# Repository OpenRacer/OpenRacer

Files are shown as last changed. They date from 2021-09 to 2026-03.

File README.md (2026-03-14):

<h3>OpenRacer - An open source frame with 3D printed canopy for racing and freestyle.</h3>
<hr>

<h3>Support OpenRacer</h3>

If you would like to support the development of OpenRacer please feel free to make a small [donation](https://www.paypal.com/donate/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). This helps us pay for prototyping/testing of carbon and canopies. When you donate, feel free to leave a comment what additions would you like to see next.

[DONATE](https://www.paypal.com/donate/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)

Full frame kits are sold by [Five33](https://flyfive33.com/products/five33-open-racer-frame-kit-1?wpam_id=17) (aff. link). You can also order the carbon from [CNC Madness](https://cncmadness.com/). We provide instructions for printing your own canopy, but if you would like one printed we recommend [Phoenix 3D](https://www.phx-3d.com/). Carbon files are for 5 inch props unless otherwise specified.

<h3>Useful Links</h3>

STL and DXF files are [here.](https://github.com/OpenRacer/OpenRacer/tree/master/cad)<br>
[Join our Facebook group](https://www.facebook.com/groups/640824090407985)<br>
[Buy frame at Five33](https://flyfive33.com/products/five33-open-racer-frame-kit-1?wpam_id=17)<br>
[Freestyle example with GP7](https://www.youtube.com/watch?v=OqChCLXAk6A)<br>
[Racing example with GP7](https://www.youtube.com/watch?v=VN75sF9umTA)<br>
[Racing full speed no gopro](https://www.youtube.com/watch?v=_SSzJq6VKVc)<br>
[DJI racing example](https://www.youtube.com/watch?v=-WxEIBV4bSs)<br>
[Review by Jon E5](https://www.youtube.com/watch?v=laAqQoRC8uU)<br>
[Step-by-step build video by Jon E5](https://youtu.be/wqulm-HaGHg)<br>
<hr>

This design was created from scratch but inspired by the brilliant CampfireQuads frame. Since the Campfire frame isn't open source and pilots wanted to improve the design to add features like support for a Caddx Vista, the OpenRacer frame was created to share with the FPV community. This design has been tested thoroughly by the community, but we're still looking for ways to improve it. Please contribute ideas or submit your own designs through pull requests!

**Note:** A lightweight variant of this frame is available – see [JM OpenRacer Light](JM_OpenRacer_Light_README.md) for details.<br><br>

<h3>Recommended carbon thickness</h3>

```
Top and Bottom plates: 2.5mm
Arms: 5mm
Braces: 4mm
```

<h3>Required screws, nuts, and standoffs</h3>

```
- 8x pressnuts M3 (for top plate)
- 4x standoffs 10mm M3 (to mount canopy) rough surface preferably
- M3 plastic nuts X 4 (to secure FC/stack)

Titanium (Grade alloy if titanium not available):
- M3 Button head 12mm X 8 (mount motors through braces and arms)
- M3 Button head 8mm X 4 (mount motors through arms)
- M3 Button head 6mm X 4 (secure canopy from the top)

Alloy Steel (12.9 Gauge Alloy - the best. 10.9 grade also works.
Not aluminium, not titanium, not stainless steel)
- M3 Countersunk 16mm X 4 (arm mounting, goes through both plates, pressnut and standoff)
- M3 Countersunk 30mm X 4 (for 30x30 stack, goes through both plates)

Additional hardware for 20x20 stack builds:
- M3 Countersunk 12.9 Grade Alloy 12mm X 4 (to lock the arms instead of 30x30 stack screws)
- M3 Button head 20mm X 4 (Titanuim or Grade Alloy) (for 20x20 stack)

Extra for 25x25 AIO:
- M2 Button head 12mm X 4
```

All canopies can be printed in 95A shore hardness TPU with the exception of the AnalogPro version. The AnalogPro canopy should be printed in Nylon. A Nylon similar to Taulman 645 is preferred, but for printers with PTFE-lined hotends limited to <250C temperatures, Taulman's lower temp alternatives such as Bridge, 230, or PCTPE are also good choices. If you are unfamiliar with Nylon printing, it has some challenges associated. Drying the filament and keeping it dry is very important, but steps for that will not be covered here.
Taulman recommends 40-60C bed temperature for PCTPE, but some people report that running even lower temperatures (35C) can help avoid warping and adhesion issues. 
Nylon prints should be boiled in water for 5 minutes to restore their flexibility.

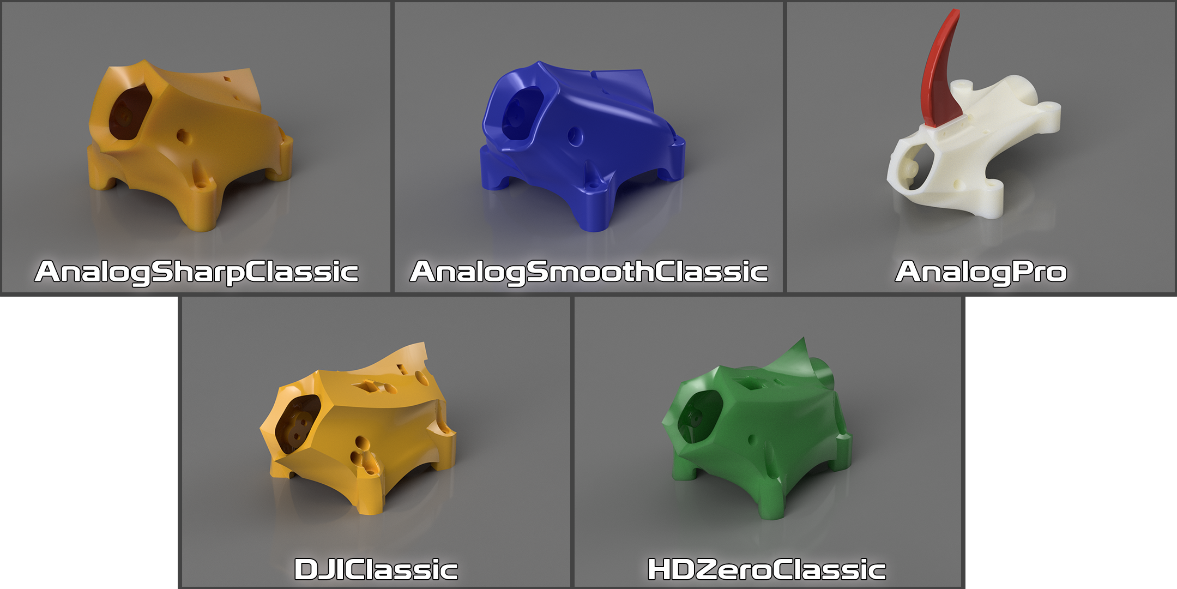
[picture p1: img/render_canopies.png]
Canopy versions


<h3>Suggested print settings for TPU canopies</h3>

```
1.6mm wall thickness (for 0.4mm nozzle, use 0.53mm line width and 3 perimeters to achieve 1.59mm walls. 0.6 to 0.8mm nozzles will use 0.8mm line width and 2 perimeters)
0.2mm layer height recommended, 0.28mm maximum
30-60% fan speed
20% infill (gyroid if available)
Supports are required
Recommended orientation is with standoff legs on the bed. It's possible to print some canopies on the nose to reduce support material, but this can be tricky and has cosmetic disadvantages.
```

<h3>Suggested print settings for Nylon AnalogPro canopies</h3>

```
1.6mm wall thickness (for 0.4mm nozzle, use 0.53mm line width and 3 perimeters to achieve 1.59mm walls. 0.6 to 0.8mm nozzles will use 0.8mm line width and 2 perimeters)
0.2mm layer height recommended, 0.28mm maximum
0% fan speed
20% infill
Supports are required, but only from build plate
Recommended print orientation is with standoff legs on bed. Use care removing supports around the antenna holder. 
```

<h3>Canopy Accessories</h3>

The AnalogPro canopy has a slot on top for an optional fin, which can help when using turtle (flip over after crash) mode. It's recommended to print this part in 95A TPU. If a camera locker is available for a canopy, it will be in the CameraLockers folder for the associated canopy. Camera lockers help maintain your camera angle in crashes and also provide some level of protection.

<p>

AnalogSharpClassic and AnalogSmoothClassic versions work with most of normal 20x20 and 30x30 stacks. 

<p>

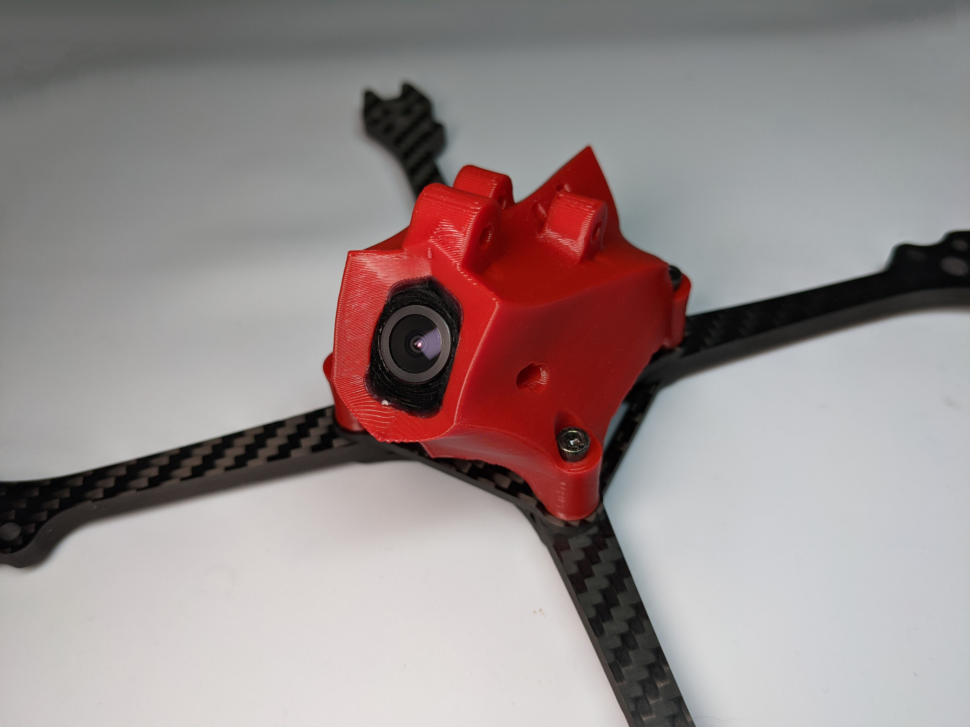
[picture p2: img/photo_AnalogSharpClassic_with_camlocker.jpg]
TPU AnalogSharpClassic

<sub>AnalogSharpClassic with optional GoPro mounts and camera locker.</sub>

<h3>Recommended components for the AnalogPro version</h3>

```
Arms style: Fatty
Canopy Style: PRO - predator nano V5
FC:        Foxeer 20x20 V2
ESC:       Foxeer Reaper 45A or 60A 20x20
Camera:    Foxeer Predator nano V5
VTX:       Rush Tiny Tank
Motors:    Vanover V2 or Headsup
Props:     Dal new Cyclone V2
Batteries: Rline v4 1300Mah 6S or any good brand like Pyroflip, GNB
Antenna:   U.FL TO SMA EXTENSION and small antenna like TrueRc
RX:        Matching RX for your radio. Ghost, Tracer, ELRS, Crossfire, etc.
Other:     Optional short race wires like Pyro race wires, zip ties, double side tape, heatshrink
```

<h3>Recommended components for the Classic versions</h3>

```
FC:        Clracing F7
ESC:       Any 30x30 Blheli32 ESC that is not very big like Spedix, Hobbywing etc. starting from 35A. Be careful, modern 30x30 Aikon and Clracing ESCs are too big. 
Camera:    Runcam Racer 3 or Foxeer Predator Micro V4
VTX:       Rush Tiny Tank
Motors:    RCINPOWER GTS-V2 2207PLUS 2207 1860KV or Vanover Motors or Talon
Props:     Gemfan 51466X3 Hurricane
Batteries: Rline v3 1300Mah 6S or any good brand like Pyroflip, GNB
Antenna:   U.FL TO SMA EXTENSION and small antenna like TrueRc
RX:        Matching RX for your radio. Ghost, Tracer, ELRS, Crossfire, etc.
Other:     Optional short race wires like Pyro race wires, zip ties, double side tape, heatshrink
```

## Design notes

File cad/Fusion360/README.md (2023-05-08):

# Fusion 360 files
These files may be used to create new canopies.
Not every canopy has an associated Fusion 360 file. To request CAD files please open an issue.

**WARNING:** Create a new folder before opening these files, as they contain many components.

## HDZero Clasic Parametric
[Download here](HDZero_Tank_V2_Parametric_v3.f3z)

This is the Fusion file for the HDZero Classic canopy.
It has parameters which let you set the size of the camera, body, lens, etc.
Please note that this is not well-tested, and currently contains parameters for the Runcam Nano 90 camera.
Activate the final two features in the design history to slice the canopy into a small printable test area.

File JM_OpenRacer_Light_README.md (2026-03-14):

# JazzMutant's OpenRacer Light

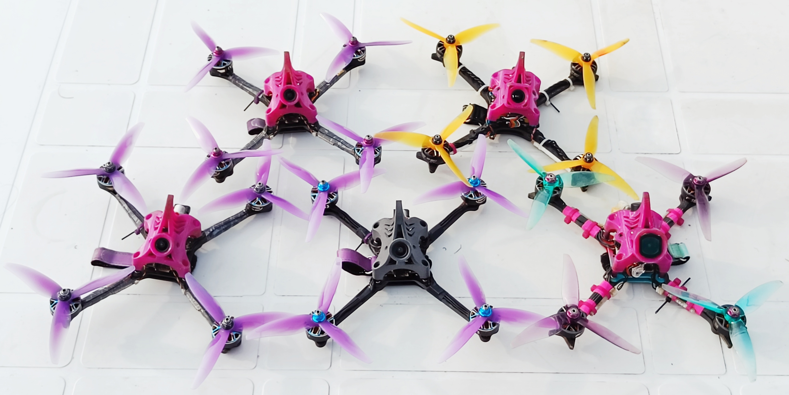
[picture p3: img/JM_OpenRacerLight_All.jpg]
JM OpenRacer Light


## Overview

The **JM OpenRacer Light** is a fully backward-compatible lightweight version of the original OpenRacer frame, designed for pilots who want reduced weight without sacrificing durability or maintainability. This version maintains full mounting compatibility with standard OpenRacer parts while implementing optimizations in the carbon structure.

This frame works best with the "OpenRacer 5 6S by JazzMutant" Betaflight preset for optimal performance.

## Canopies 

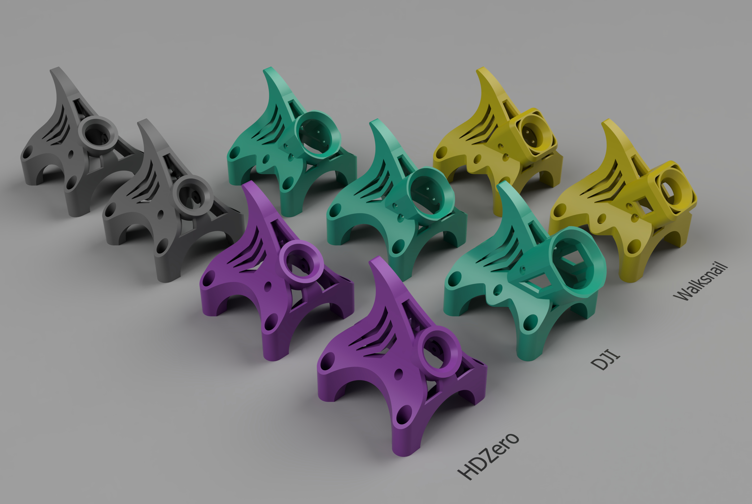
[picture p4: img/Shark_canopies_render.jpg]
Shark Canopies


This frame works with all existing OpenRacer canopies. In addition, **@jares13** have disigned the **Shark Canopies** which are lighter than the standard designs and remain extremely durable. They also feature an integrated fin for turtle‑mode recovery.

### Options
```
- HDZero Race V3 + Nano 90 v2 + Rush Cherry v2. (45° or 55°)
- DJI O3 (45°)
- DJI O4 light + O3 lens (45°)
- DJI O4 pro + O3 antenna (45°)
- Walksnail Avatar Pro (45°)
- Walksnail Avatar v2 (45°)
```

If you need more canopy variants for specific hardware or personal preference, a **Fusion 360 project** is provided to let you customize or generate additional designs.

### Printing Recommendations

All canopies for the Light frame should be printed in **95A TPU**.
There is also an HDZero version optimized for PA-11 nylon which is thinner and lighter. For nylon printing, services such as PCBWay and JLC3DP are recommended.

## Hardware Specifications

### Carbon

```
Top Plate:          2mm
Bottom Plate:       2mm
Arms:               5mm
Braces (optional):  3-4mm
```

**Important**: All carbon components should be **T700 carbon fiber** to compensate for the reduced thickness and ensure optimal strength-to-weight ratio. Braces are optional and can be either 3mm or 4mm thick depending on your build preference.

### Required Hardware

**HDZero Race V3 with 20x20 stack**
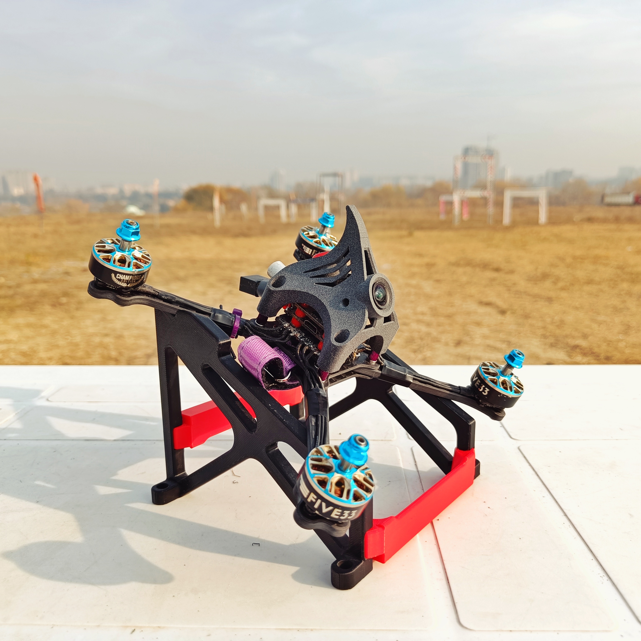
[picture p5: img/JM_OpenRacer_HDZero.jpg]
JM OpenRacer HDZero

```
8 psc   M3 pressnuts (for top plate)
4 psc   M3 nut (for stack screws. Titanium)
4 psc   M3x25mm button head screw (for stack mounting. Titanium)
4 psc   M3x10mm countersunk screw (for arm mounting. 12.9 grade alloy steel)
4 psc   M3x16mm countersunk screw (for arm and standoff mounting. 12.9 grade alloy steel)
4 psc   M3x6mm button head screw (for canopy mounting. Titanium)
12 psc  M3x8mm button head screw (for motors mounting. Titanium)
4 psc   M3x10mm standoff.
```

**DJI/Walksnail with 20x20 stack**
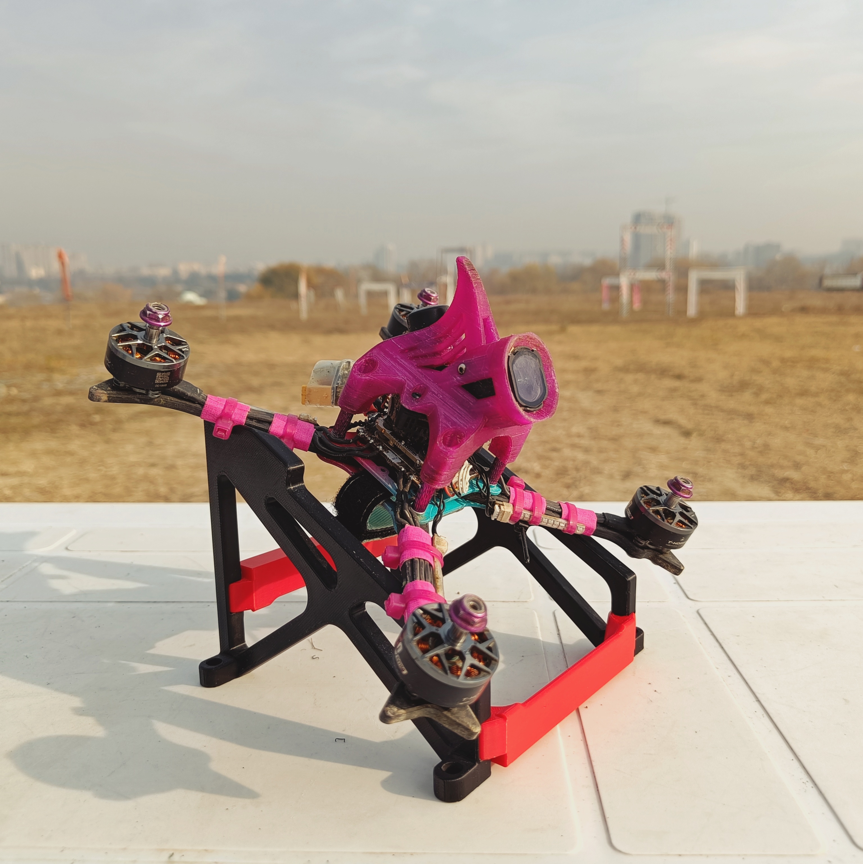
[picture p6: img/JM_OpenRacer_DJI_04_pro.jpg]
JM OpenRacer DJI 04 pro

```
8 psc   M3 pressnuts (for top plate)
4 psc   M3 nut (for stack screws. Titanium)
4 psc   M3x18mm button head screw (for stack mounting. Titanium)
4 psc   M3x10mm countersunk screw (for arm mounting. 12.9 grade alloy steel)
4 psc   M3x16mm countersunk screw (for arm and standoff mounting. 12.9 grade alloy steel)
4 psc   M3x6mm button head screw (for canopy mounting. Titanium)
12 psc  M3x8mm button head screw (for motors mounting. Titanium)
4 psc   M3x15mm standoff.
```

**Optional hardware**
```
8 psc   M3x12mm button head screw (for motor mounting if you use braces)
8 psc   M3x28mm countersunk screw (for arm and stack mounting if you use 30x30 stack. 12.9 grade alloy steel)
4 psc   M2x12mm button head screw (for AIO mounting)
```

**Notes:**
- Use 12.9 grade alloy steel for arm mounting. Anything else would not work.
- Titanium is recommended for best weight savings but can be replaced with steel.

## Reference Builds

> **Disclaimer:** these example builds are provided for illustration only and use different component sets; they should not be treated as directly comparable or definitive "best" configurations.

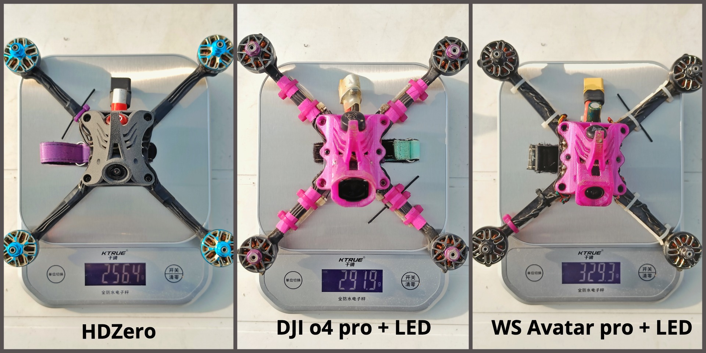
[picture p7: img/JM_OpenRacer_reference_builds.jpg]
Reference Builds


### HDZero

- Frame: JM OpenRacer Light
- Stack: Oxbot Champ (20×20)
- Motors: Five33 2207 2070 KV
- Camera: HDZero Nano 90 V2
- VTX: HDZero Race V3
- Antenna: Rush Cherry V2
- RC: Radiomaster XR1
- Canopy: Shark Canopy (Nylon)

**Weight: 256.4g**

---

### DJI O4 Pro

- Frame: JM OpenRacer Light
- Stack: HDZero Halo (20×20)
- Motors: T-Motor F50 2207 2150 KV
- Camera: DJI O4 Pro
- VTX: DJI O4 Pro
- Antenna: DJI O3
- Canopy: Shark Canopy (95A TPU)
- Other: HGLRC LED Kit

**Weight: 291.9g**

---

### Walksnail Avatar Pro

- Frame: Default OpenRacer (steel hardware)
- Stack: SpeedyBee V4 (30×30)
- Motors: iFlight XING E-Pro 2207 2450 KV
- Camera: Walksnail Avatar Pro
- VTX: Walksnail Avatar Pro
- Antenna: Walksnail
- RC: Happymodel EP1
- Canopy: Shark Canopy (95A TPU)
- Other: LED Kit

**Weight: 329.3g**
This is a temporary file containing the Flight Videos section to append to the README.

## Flight Videos

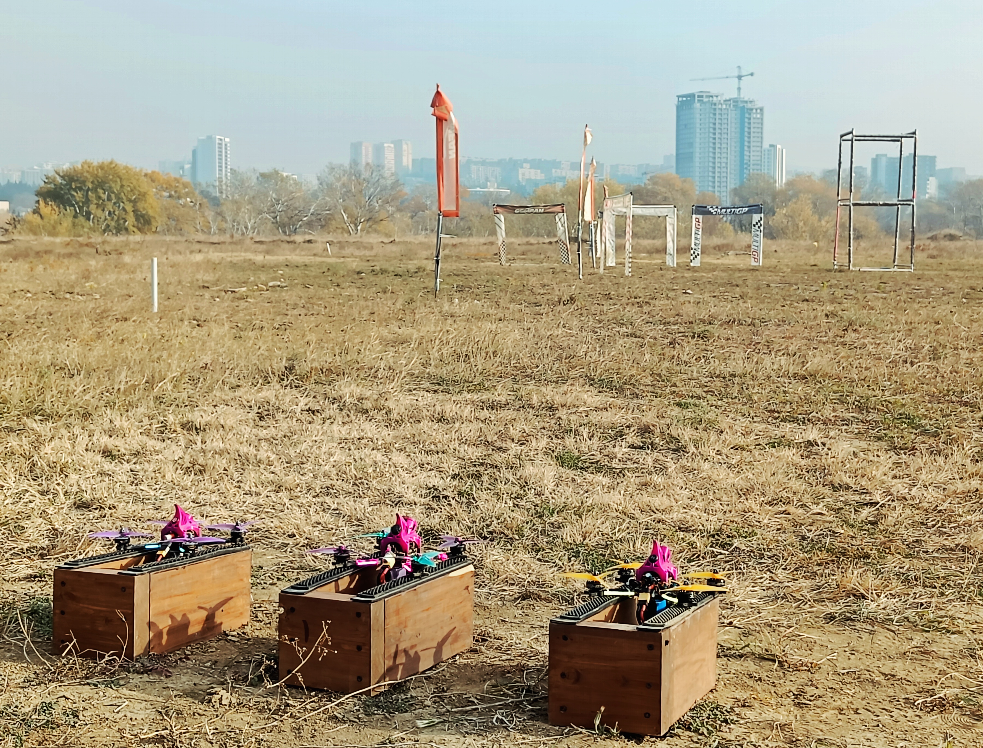
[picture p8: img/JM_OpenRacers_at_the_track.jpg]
JM OpenRacers at the track


Here are some flight footages from our practice sessions:
- [Sunday Mayhem](https://youtu.be/KUW6h_FZijc)

- [NIGHT PRACTICE](https://youtu.be/jPU3IjdKNmI)

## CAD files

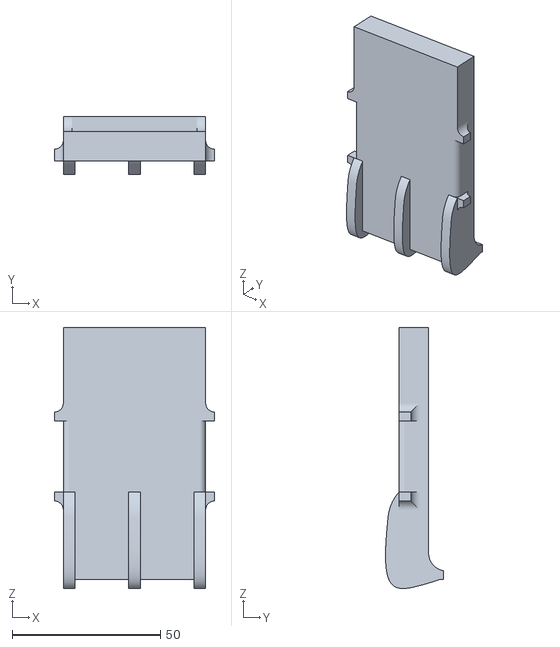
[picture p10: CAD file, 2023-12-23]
cad/Accessories/6S_LiPo_Coffin_Wider.stl
54.0 x 19.5 x 88.0

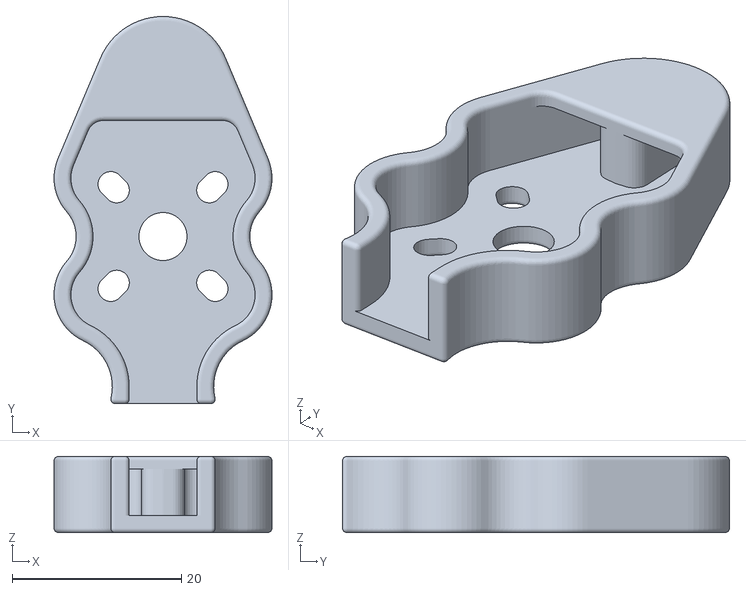
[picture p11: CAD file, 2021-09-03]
cad/Accessories/ShoesTpu/ClassicArms/4holesArmShoe.stl
25.8 x 45.8 x 9.00

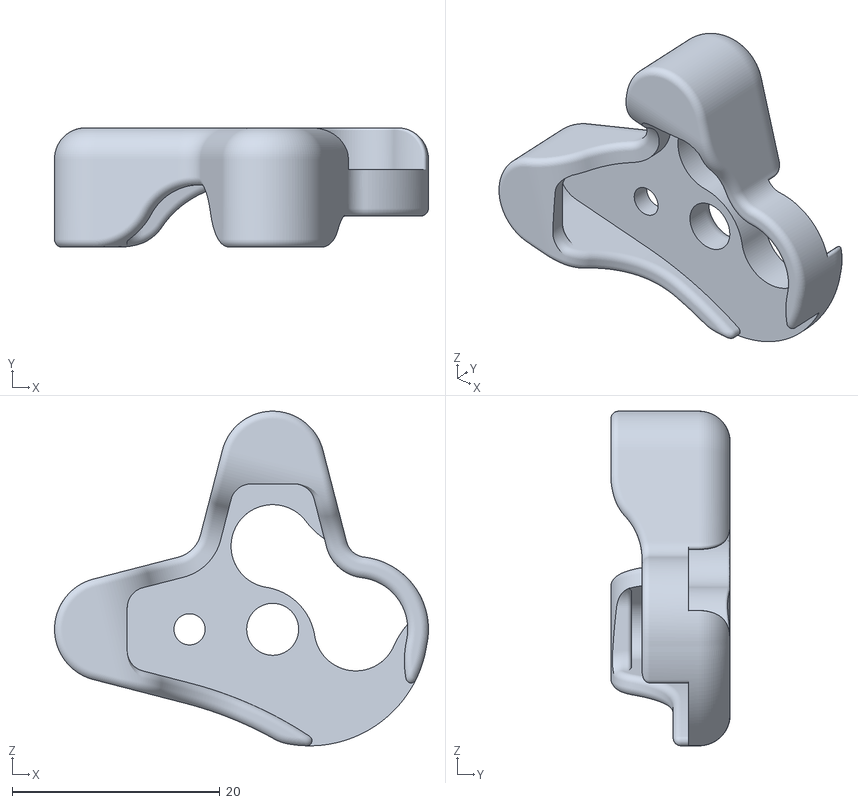
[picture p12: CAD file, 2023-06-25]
cad/Accessories/ShoesTpu/XvOrFattyArms/Xvlite_shoe.stl
36.0 x 11.5 x 32.2

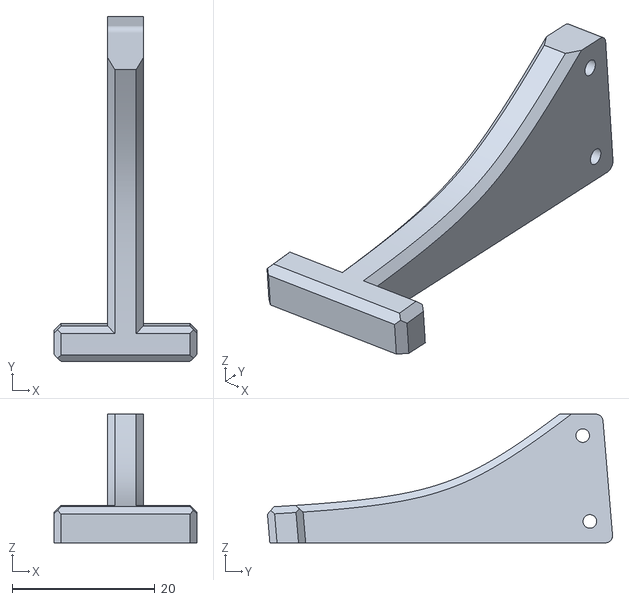
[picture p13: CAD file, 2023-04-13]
cad/AnalogPro/Fins/T-fin.stl
20.0 x 48.3 x 18.0

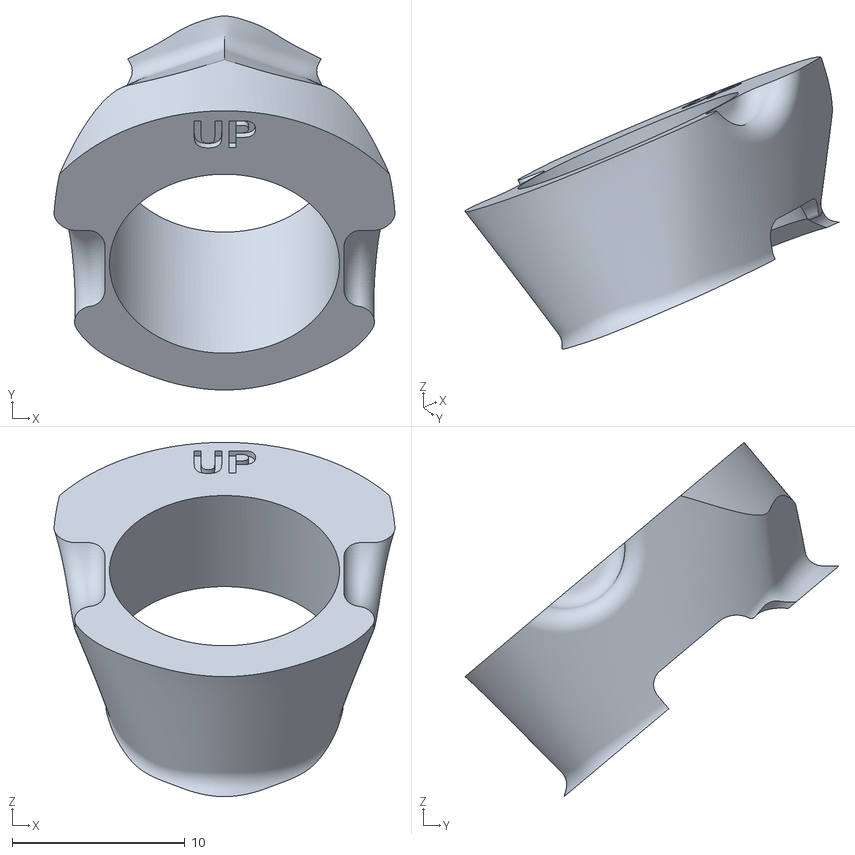
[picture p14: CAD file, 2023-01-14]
cad/AnalogPro/FoxeerPredatorNano5/30-45_cam_degrees/CameraLockers/1.7lens/50.stl
19.7 x 21.6 x 20.5

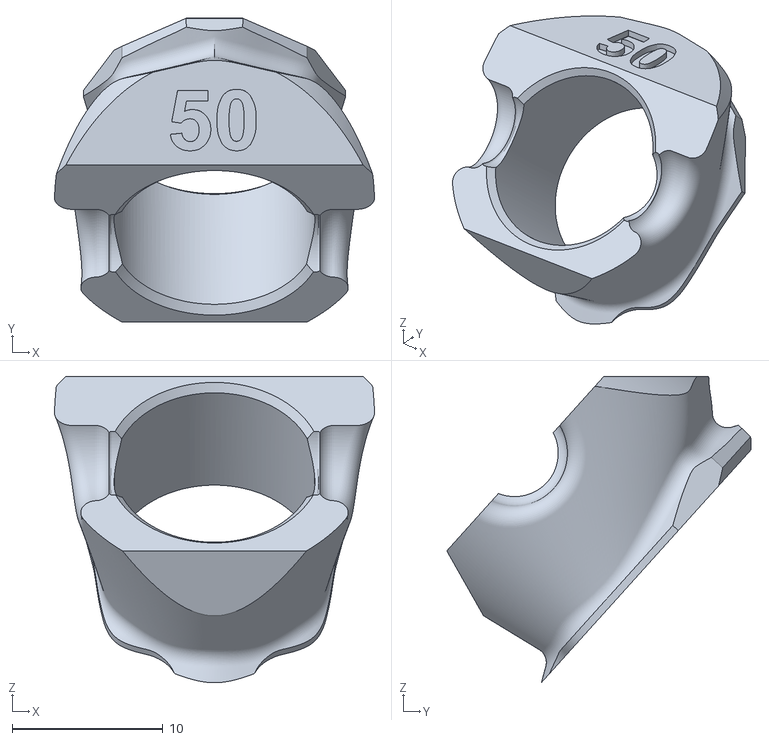
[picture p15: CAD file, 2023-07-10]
cad/AnalogPro/FoxeerPredatorNano5/45-55_cam_degrees/CameraLockers/50.stl
21.2 x 20.2 x 20.3

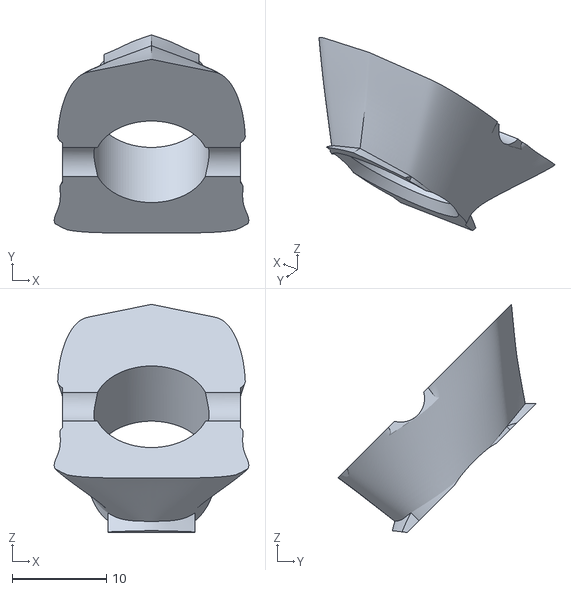
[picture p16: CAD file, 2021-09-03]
cad/AnalogPro/RuncamRacer3/CameraLockers/45.stl
20.6 x 20.9 x 24.1

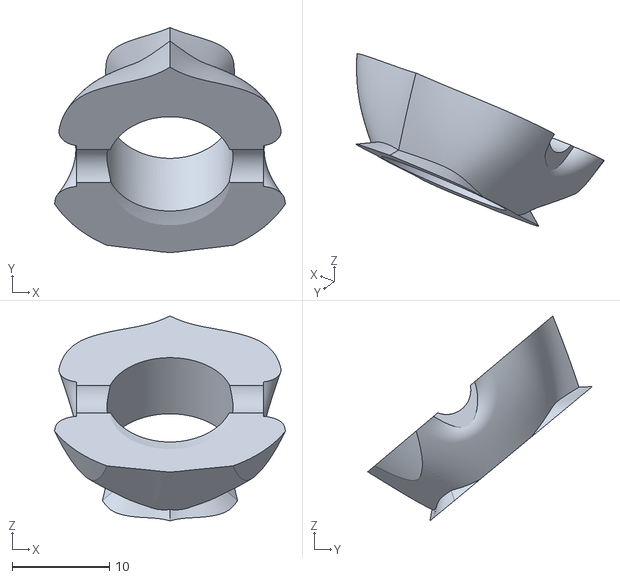
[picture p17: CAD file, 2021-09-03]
cad/AnalogSharpClassic/CameraLockers/Foxeer13mmLens/45.stl
23.8 x 23.1 x 21.1

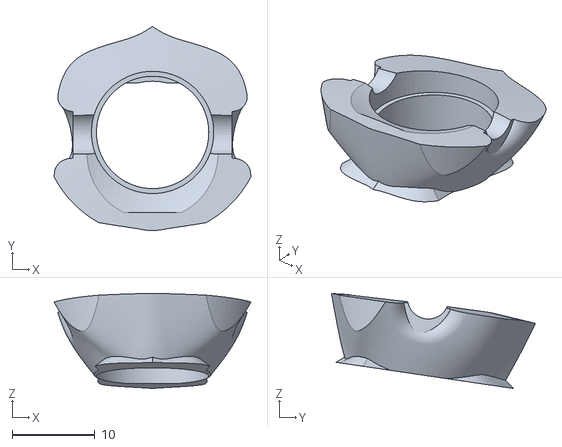
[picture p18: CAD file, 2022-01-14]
cad/AnalogSharpClassic/CameraLockers/RuncamPhoenix2/48.stl
23.8 x 24.7 x 11.5

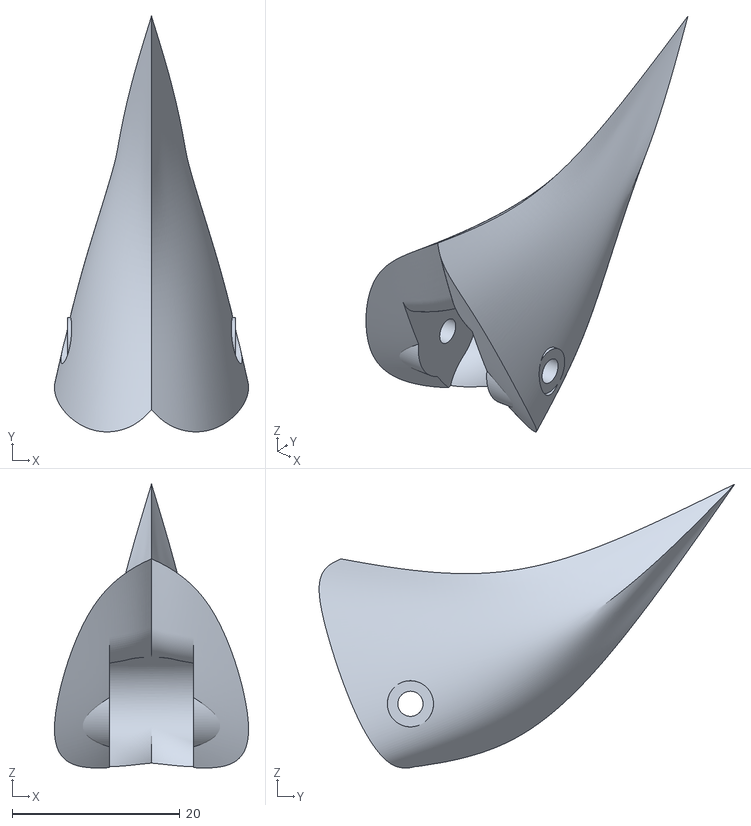
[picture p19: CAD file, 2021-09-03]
cad/AnalogSharpClassic/Fins/SharkTooth.stl
23.1 x 49.6 x 33.9

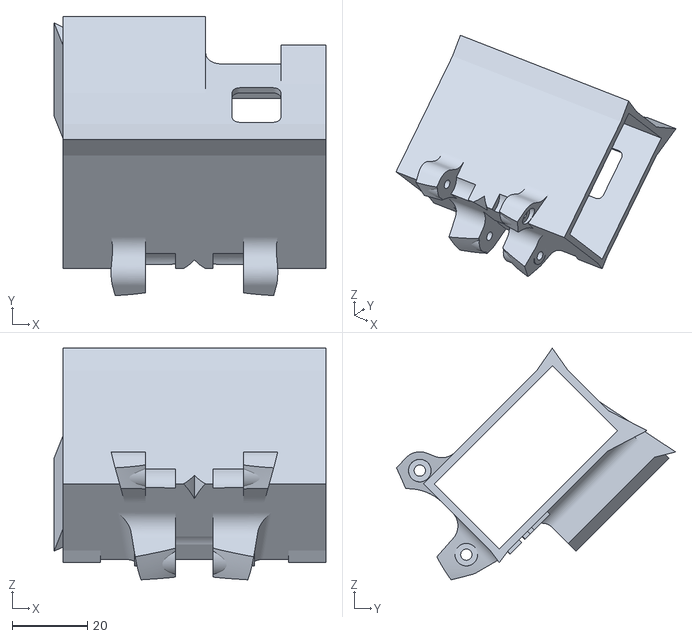
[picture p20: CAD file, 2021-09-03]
cad/AnalogSharpClassic/GoproCases/Gopro7/45.stl
72.4 x 74.3 x 61.6

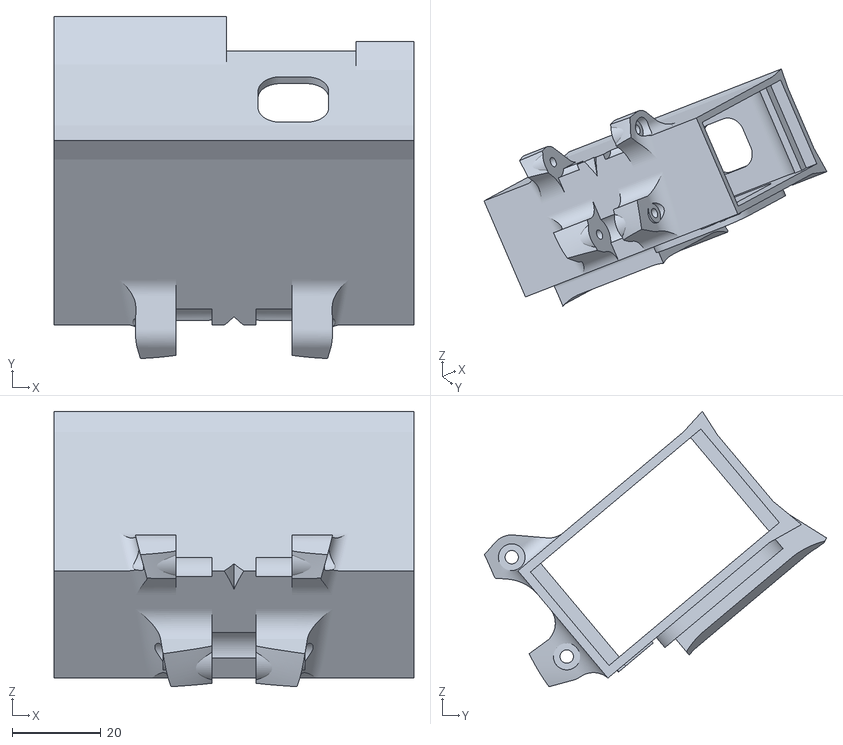
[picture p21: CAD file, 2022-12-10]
cad/AnalogSharpClassic/GoproCases/Gopro9_10_11/40.stl
81.0 x 77.0 x 62.0

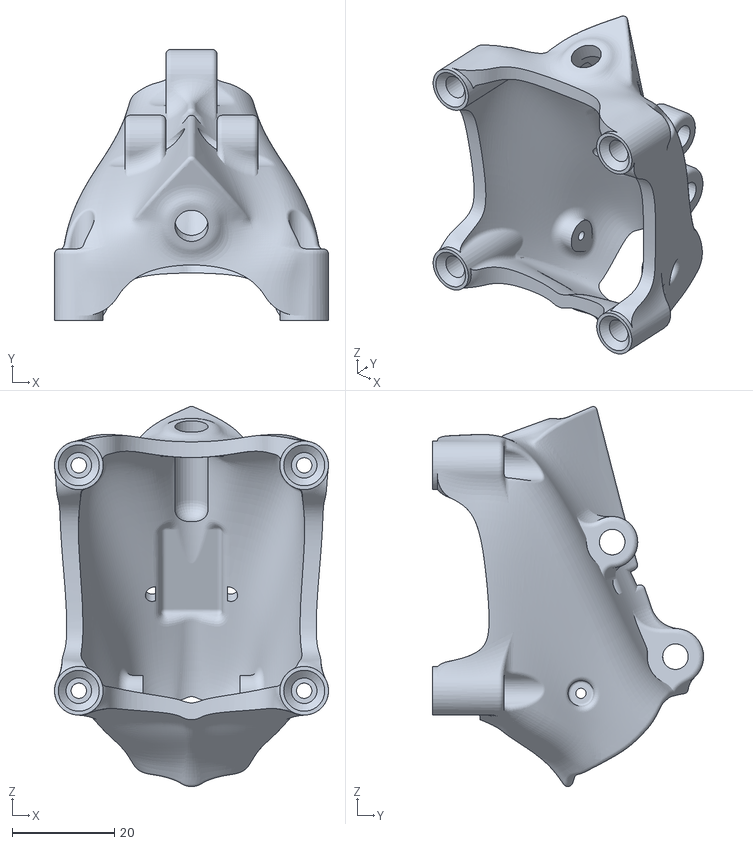
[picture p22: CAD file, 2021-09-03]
cad/AnalogSmoothClassic/CanopyGoproMounts.stl
53.5 x 52.9 x 74.2

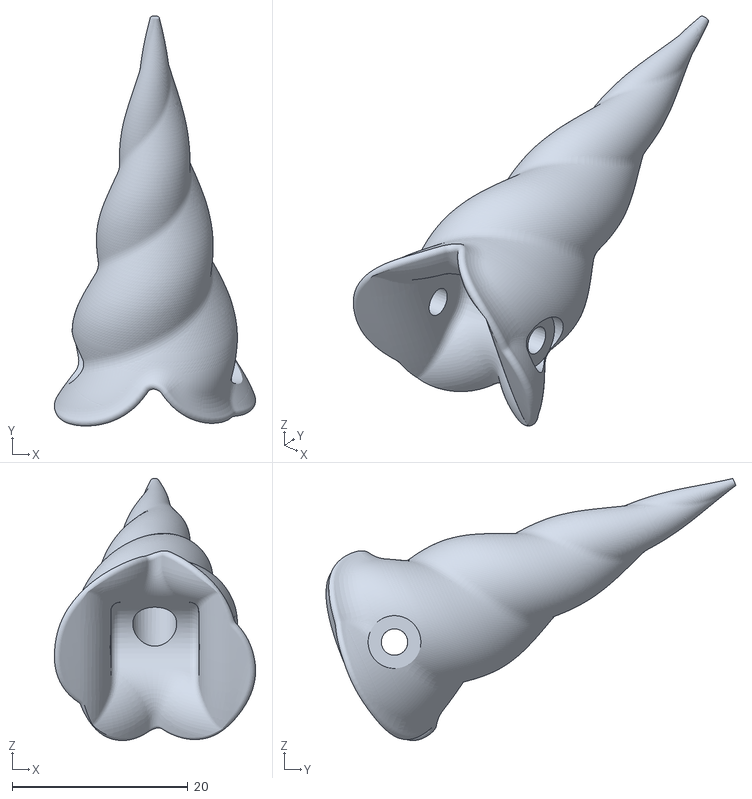
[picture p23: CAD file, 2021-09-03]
cad/AnalogSmoothClassic/Fins/UnicornMagic.stl
22.9 x 46.6 x 29.8

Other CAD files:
cad/AnalogSharpClassic/CameraLockers/RuncamRacer3Micro/45.stl
cad/AnalogSmoothClassic/GoproMounts/Session5.stl
cad/Carbon/2mm_MidPlate_JM_Light.step
cad/Carbon/Arms/5mm_Arm_JM_Light.step
cad/Accessories/6S_LiPo_Coffin.stl
cad/Accessories/CrossfireImmortalMount.stl
cad/Accessories/ShoesTpu/ClassicArms/3holesArmShoe.stl
cad/Accessories/ShoesTpu/ClassicArms/3holesArmShoeMotorGuard.stl
cad/Accessories/ShoesTpu/ClassicArms/4holesArmShoeMotorGuard.stl
cad/Accessories/ShoesTpu/XvOrFattyArms/XvTpuShoes_Left.stl
cad/Accessories/ShoesTpu/XvOrFattyArms/XvTpuShoes_Right.stl
cad/AnalogPro/FoxeerPredatorNano5/30-45_cam_degrees/CameraLockers/1.7lens/35.stl
cad/AnalogPro/FoxeerPredatorNano5/30-45_cam_degrees/CameraLockers/1.7lens/40.stl
cad/AnalogPro/FoxeerPredatorNano5/30-45_cam_degrees/CameraLockers/1.7lens/45.stl
cad/AnalogPro/FoxeerPredatorNano5/30-45_cam_degrees/CameraLockers/1.7lens/48.stl
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

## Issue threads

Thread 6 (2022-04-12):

Create canopy and cameralockers for hdzero micro v2

ouky, 2022-04-12:
Can somebody create this? Or can i get the sourcefiles and do it myself?

limonspb, 2022-05-12:
> Can somebody create this? Or can i get the sourcefiles and do it myself?

sorry, just saw your message.
I could be wrong but HDZero v2 camera works ok with HDZero v1 canopies as well as its pretty similar size.
So this one:
https://github.com/OpenRacer/OpenRacer/tree/master/cad/HDzero_Race2/Full_Canopy/Runcam_micro_stock_lens

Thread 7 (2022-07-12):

XV Arm Lite 5"

MrRemmers, 2022-07-12:
I purchased a frame with XV Lite 5" arms; I don't see a DXF file for those arms in this repo.  Is this arm something designed by CNCdrones and not merged with this project?  It would be nice to have the design file for this arm to play with in CAD.

d3c0deFPV, 2022-09-16:
Hi @MrRemmers I've added the "lite" version of the XV arm. It's available here https://github.com/OpenRacer/OpenRacer/tree/master/cad/Carbon/Arms with the filename 5mm_Arm_XV_3Holes.dxf. XeroVolume also has them available on Thingiverse. https://www.thingiverse.com/thing:4597110/files

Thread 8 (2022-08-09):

How it compares to other popular racing frames by weight?

jurgelenas, 2022-08-09:
Hey!

I think it would be nice to add weight comparison table in README.md.

limonspb, 2023-04-23:
with so many canopy variations, it is a lot of work to make such table.
Also depends on where you buy the screws/hardware from

flexd, 2023-08-25:
I'd be interested in knowing the rough weight what people are ending up with as well. My analog classic sharp pod quad is about 296g without any braces (and no prop nuts/props). XV arms, normal steel hardware, xnova lite 2207, hobbywing esc, aikon f7. Predator nano V5 and a OpenVTX.

How much weight do you save with the pro pods, if any? What configurations/setups do people usually use? I have not tried printing any Nylon/PCTPE yet, but once I can manage to actually buy some here I'll give the pro pods a try.

By the way would a Discord or some other chat like that to talk about the frame and things like that be something more are interested in? Even just a channel on some other Discord. Facebook groups aren't great

limonspb, 2023-09-01:
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

Py analog PRO fresh builds are about 285-290g with 2207 headsup motors (no-mr30), HQ R38 props, chunky foxeer 50A ESC 20x20, 20x20 foxeer FC, ghost hybrid board, fatty arms, stainless steel screws for motor mounting, no braces, 533 sticky battery bad, short ESC wire (12AWG), foxeer predator nano 5 camera, turtle fin. Conformal coated + some B7000 glue to hold soldering joints + plugs, 20mm wide battery strap with metal buckle, UFL lollipop foxeer antenna.

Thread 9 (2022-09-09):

Requesting 4" and 3" arm options and 20x20 only body options that are interchangeable with current parts.

raymondes, 2022-09-09:

d3c0deFPV, 2022-09-18:
Hi @raymondes. A 4 inch arm option seems reasonable and should work well with the current bottom/top plate. I just had a chat with XeroVolume and he provided a variant of this since it's an easy change (cad/Carbon/Arms/5mm_Arm_XV_4_Inch.dxf). This currently has 16x16mm mounting holes, but we can add 12x12 as well, and matching braces.

A 20x20 only bottom/top plate seems like it would be a considerable amount of work, especially when considering that means redesigning pods, cam lockers, and potentially other accessories. I don't think that 3" arms would be viable without shrinking the main body and pod down. At this time I don't think anyone is willing to pick this part of the request up, but if you can do it I'd be happy to add it to the repo.

d3c0deFPV, 2022-09-19:
Just added a 12x12mm motor mount version of the 4 inch arm and braces for both 12x12 and 16x16. (Thanks XeroVolume)

raymondes, 2022-09-19:
You are 100% right about 3 inch and 20x20 only frame. Unfortunately I don't have the skill to do it myself. I'm very grateful for the 2 versions of the 4 inch arms. Consider this issue closed.

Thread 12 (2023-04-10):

Add USB cutout to O3 canopys

jasc76, 2023-04-10:
A cutout for the FC USB port would be nice

limonspb, 2023-04-23:
For the O3 unit OSD - its there.
As for the flight controller - its difficult.
Because everyone builds differently, so everyone has FC USB in all different places. So will have to cut a lot on both sides.

jasc76, 2023-04-23:
Fair….
Cut two times and its still too short 😄

i will just mod it and make it fitting for my fc

another thought was: why not have some bracket so the O3 could just be pushed in from the bottom. Currently you have to slide it in. Maybe easier and even more secure.

closed.

limonspb, 2023-04-23:
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

for the bracket, i was thinking about something like that but could not figure out the exact implementation

jasc76, 2023-04-23:
I would extrude 4 posts from the top that wrap around the O3 corners and have a bulge at the bottom to hold the O3 up

jasc76, 2023-04-23:
You need supports anyway so this is no downside

limonspb, 2023-04-24:
> I would extrude 4 posts from the top that wrap around the O3 corners and have a bulge at the bottom to hold the O3 up

i can't understand what you proposing without the drawing

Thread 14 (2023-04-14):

Add canopy source STEP files

robhaswell, 2023-04-14:
OpenRacer provides STL files for its canopies and lockers, but this is not an "open" format and is akin to shipping compiled binaries. The STL files can be used but editing them is problematic at best, as they have been compiled down to triangles and details such as the fillets, projections, etc have been lost.

It would be great if the source CAD files could be uploaded in an editable format, e.g. STEP or the native format of a widely accessible CAD software like Fusion. The canopies are a large part of the overall frame and allowing users to edit them can only bring benefits to the project.

limonspb, 2023-04-20:
there are lotsand lots of files/canopies. So im just giving them on demand in whatever format you like.
What canopy are you interested in?

robhaswell, 2023-04-20:
That would be great - thanks. I'm mainly interested in making an Nano90 Classic, so whatever is close to that, I would also like to make some small modifications to the Nano90 Pro. I also want to make one for Walksnail so probably the Vista pod is closest to that.

One of the camera lockers would be good as well, I can probably modify just one.

Please could you send them in something I can load into Fusion 360, maybe STEP, or any other free CAD software so I can open them up. Thanks!

limonspb, 2023-04-23:
Sorry, a few days late.
this is PRO Hdzero nano 90:
https://drive.google.com/file/d/1pW9J78KofWkMK_4MHuWfZwMmcR0p2MqG/view?usp=share_link

uploading others...
its fusion 360 format.
The problem with STEP - its not easy to modify... the problem with fusion 360 format - its really long process to export for whatever reason... They removed the ability to share a link from the free versions :/

limonspb, 2023-04-23:
Classic HDZero Runcam Nano canopy (fusion 360 format)
https://drive.google.com/file/d/1Ni-tkZ5jCdnCcezemONlrfmZabkeVe8s/view?usp=share_link

limonspb, 2023-04-23:
DJI O3 canopy - could be the closes to walksnail:
https://drive.google.com/file/d/1RYrezc8Wb_teqbTwLZSnPBn9lSPifbR1/view?usp=share_link

limonspb, 2023-04-23:
@robhaswell make sure that before importing you create a separate folder in Fusion 360, because importing these files creates a bunch of little subfiles with all separate components...

robhaswell, 2023-04-23:
Awesome, thanks @limonspb

Closed 2023-05-08.

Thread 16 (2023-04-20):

Improve documentation

robhaswell, 2023-04-20:
I'm willing to undertake some work to improve the documentation for this project, but would like to discuss this with the maintainers before starting. Things that come to mind are:

* Document the various different arm styles and what they mean.
* Build guide and tips harvested from the current userbase.
* Better discovery of canopies (see #15).
* Surface the various accessories such as fins, mounts and shoes.
* Document any learnings on carbon cutting and canopy printing.

I'm best available on Discord as Mopatop in most of the community FPV servers.

limonspb, 2023-04-23:
im all for it Sir! :)
Repo is opened for the pull requests.

- Document the various different arm styles and what they mean. - GOOD!
- Build guide and tips harvested from the current userbase. - GOOD!
- Better discovery of canopies (see https://github.com/OpenRacer/OpenRacer/issues/15). - QUESTIONS
- Surface the various accessories such as fins, mounts and shoes. - GOOD!
- Document any learnings on carbon cutting and canopy printing - GOOD!

As for the canopies - there is a problem with different cameras. Lots of times it's not just a different camera locker, but a little different canopy shape itself, to make sure there is nothing in camera view for various angles and still OK camera protection...

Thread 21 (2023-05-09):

Add .step cad files to their .stl counterparts

s52mp, 2023-05-09:
Modifying .stl parts to fit my hardware is pain it would be nice to have the files in a format that can be edited.

limonspb, 2023-05-19:
some fusion 360 files are here:
https://drive.google.com/drive/folders/1HOByzfjuoB_mvtBGb6IyWwKg5R3Pp1S1?usp=sharing

let me know if you need anything specific. Its a lot of different canopies. Since fusion blocked file sharing on the free version, it became a pain...

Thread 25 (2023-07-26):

O3 canopy: air unit shifts forward in crashes

alteman, 2023-07-26:
The retaining bumps on the top of the canopy aren't high enough to prevent the AU from shifting forward in a crash. Since it's printed in TPU, the canopy should be bent inwards and the unit should force the canopy outwards, creating static forces that would help with retention. Same goes for the bumps that hold the unit up - they need to be stressed when in normal position. As is, the fit is not snug, and O3 heating up the TPU doesn't help a bit. I'd like a version with both sides and the lower 'retaining bumps' warped towards the center, for a snugger fit. Also won't hurt extending the topmost retaining indents to cover the whole AU height, not just the top 2-3mm.

Another possibility would be an internal zip tie to cinch sides together..

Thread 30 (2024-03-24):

O3 Canopy Fusion 360 Files

lbarinov, 2024-03-24:
Was hoping you could share the fusion 360 file for the DJI o3 canopies, so that I can make some modifications for FC ports without having to import the stl directly.

limonspb, 2024-05-06:
Hey!
There we go:
https://drive.google.com/drive/folders/1HOByzfjuoB_mvtBGb6IyWwKg5R3Pp1S1?usp=sharing

andyland1, 2025-04-20:
Is it possible to share fusion files for the latest HDzero_Race3 HDzero PRO canopies for 40-60 degrees and upgraded lens?
Need for both lens version.

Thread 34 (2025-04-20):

HDzero PRO canopies fusion files

andyland1, 2025-04-20:
Is it possible to share fusion files for the latest HDzero_Race3 HDzero PRO canopies for 40-60 degrees and upgraded lens?
Need for both lens version.

MeatG, 2025-04-20:
would be interested too!

lesharodin, 2025-05-11:
look here https://github.com/OpenRacer/OpenRacer/issues/30

MeatG, 2025-05-15:
> look here [#30](https://github.com/OpenRacer/OpenRacer/issues/30)

Thanks, but those are old versions from 2023 :/

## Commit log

2021-09-03 initial stl+dxf files upload
    [2.5mm_BottomPlate.dxf, 2.5mm_MidPlate.dxf, 30.stl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]
2021-09-16 Sharp Classic Pod: added more room for ESC and FC connectors in front of the frame
2021-11-19 Moving XV brace up a directory
    [openracer_xv_brace_5.5_inch_4mm.dxf]
2021-11-30 HD zero race 2 canopies (Runcam micro camera)
    [45.stl, 48.stl]
2021-12-01 HDZero runcam nano full canopy version
    [45.stl, 48.stl]
2021-12-09 Added print settings and corrected typos
    Also some formatting changes
2021-12-22 Adding donate button
2021-12-22 Readme: Extra line before donate button
2022-01-14 Add Cam Locker for RunCam Phoenix
    [48.stl]
2022-01-14 Add Runcam Phoenix 2 cam locker
    [48.stl]
2022-02-01 Carbon folder files renamed for consistentcy
    [4mm_Brace.dxf, 4mm_Brace_XV_5.5_Inch.dxf, 4mm_Brace_XV_6_Inch.dxf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]
2022-02-01 Carbon files are for 5 inch props unless otherwise specified
2022-05-16 Analog PRO canopy updates: 1mm taller, 1mm taller + thicker fin mount, 1mm taller + no antenna nount
2022-05-16 HDZero_race2 48 dgegreed camera locker for runcam 4x3
    [48.stl]
2022-08-13 Delete 40.stl
    Mounting is wrong dimensions for AnalogSharpClassic pod. 30 and 45 look ok
    [40.stl]
2022-09-10 Added Pro pod for HDZero Race V2 + Runcam nano V2
    [35.stl, 40.stl, 45.stl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]
2022-09-12 Added lipo coffin - 6S battery protector
    [6S_LiPo_Coffin.stl]
2022-09-16 Adding 3 hole XV arm (aka lite)
    [5mm_Arm_XV_3Holes.dxf]
2022-09-18 Adding 4 inch variant of XV arm
    [5mm_Arm_XV_4_Inch.dxf]
2022-09-19 Adding braces and 12x12mm arm motor option for 4 inch
    [4mm_Brace_XV_4inch_12x12mm.dxf, 4mm_Brace_XV_4inch_16x16mm.dxf, 5mm_Arm_XV_4_Inch_12x12mm.dxf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]
2022-12-10 Added gopro 9+10+11 cases for classic analog canopy
    [25.stl, 30.stl, 35.stl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]
2023-01-05 Analog PRO predaor canopy cleanup and 5.4mm holes for standoffs
2023-01-05 Canopy HDZero Runcam Nano v2 - 5.4mm standoff holes
2023-01-05 Added HDZero Nono 90 PRO pod with 48 deg cam locker
    [48.stl]
2023-01-05 Analog sharp classic: 5.4mm standoff holes + small slots for big ESCs
2023-01-14 Analog pro - predator nano V5 - update camlockers: make them less tight
    [35.stl, 40.stl, 45.stl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]
2023-01-14 Added DJI O3 canopy (20x20 stack classic, 5.4mm holes)
2023-01-14 DJI O3 classic canopy: added binding hole
2023-02-17 Added 35 - 52 cam lockers for HDzero Pro 90 canopy
    [35.stl, 40.stl, 45.stl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]
2023-04-04 Add nylon printing advice
2023-04-04 Update PCTPE bed temp instructions
2023-04-13 Add T-fin file.
    [T-fin.stl]
2023-04-27 Add HDZero Nano 90 camera option for the Classic canopy. Closes OpenRacer/OpenRacer#10.
    [45.stl, 48.stl]
2023-06-25 Added stl for XV lite arm.
    [Xvlite_shoe.stl]
2023-07-10 Added analog PRO canopy for 45-55 degrees camera anles (predator nano V5)
    [35.stl, 40.stl, 45.stl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]
2023-12-23 Lipo coffin for MCK V2 battery which is wider and a bit longer
    [6S_LiPo_Coffin_Wider.stl]
2024-06-09 HDzero PRO canopies for 40-60 degrees and upgraded lens
    [Locker 45 - HDZero Race V3 PRO 40-60 RC18D.stl, Locker 45 - HDZero Race V3 PRO 40-60.stl, Locker 50 - HDZero Race V3 PRO 40-60 RC18D.stl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]
2025-01-21 DJI O4 Pro locked camera angles 35, 40, 45, 48, 50
2026-02-02 cleaned up the directories
    [6S_LiPo_Coffin.stl, 6S_LiPo_Coffin_Wider.stl, Locker 45 - HDZero Race V3 PRO 40-60 RC18D.stl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]
2026-03-02 Add JM OpenRacer light and Shark canopies
    [2mm_BottomPlate_JM_Light.step, 2mm_MidPlate_JM_Light.step, 5mm_Arm_JM_Light.step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]
